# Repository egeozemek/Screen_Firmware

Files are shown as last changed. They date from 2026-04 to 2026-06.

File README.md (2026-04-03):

# Tympanometer

A low-cost tympanometer designed to diagnose hearing loss in children, developed as part of the [Duke BME Design Fellows](https://bme.duke.edu/academics/undergrad/design-fellows/) program at Duke University's Pratt School of Engineering under the supervision of [Dr. Mark Palmeri, MD PhD](https://github.com/mlp6).

- [Duke BME Designers Develop a New Tool to Inexpensively Diagnose Hearing Loss in Children](https://pratt.duke.edu/news/duke-bme-designers-develop-a-new-tool-to-inexpensively-diagnose-hearing-loss-in-children/)
- [Preventing Childhood Hearing Loss Worldwide](https://pratt.duke.edu/news/preventing-childhood-hearing-loss-worldwide/)

---

## Team

**Iris Ye** · **Alisha Gupta** · **James Mu**



---

## Repository Structure

This repo has three active branches, one per contributor:

| Branch | Owner | Focus |
|---|---|---|
| `main` | James Mu | Firmware, OLED display integration, microphone PCB |
| *(Alisha's branch)* | Alisha Gupta | Audio/microphone analog circuit PCB |
| *(Iris's branch)* | Iris Ye | Isolated microphone PCB and analog filtering |

---

## What We've Built

### Firmware & OLED Display — James Mu

Integrated a GME12864-13 (128×64 SSD1306) OLED display into the device running on the nRF52833 DK under Zephyr RTOS. The display renders a real-time tympanogram trace with a split-zone layout:

- **Yellow zone (rows 0–15):** ear canal volume (ECV), static admittance (SA), and peak pressure (PPP)
- **Blue zone (rows 16–63):** tympanogram curve plotted from −400 to +200 daPa

The firmware supports all five standard tympanogram curve types (A, As, Ad, B, C) and currently uses physiologically accurate simulated data. Real ADC input will replace the simulation when the analog front-end is complete.

A custom 3×5 bitmap font is used to minimize flash footprint.

**Hardware:**
- MCU: nRF52833 DK
- Display: GME12864-13 OLED (SSD1306, I2C at 0x3C)
- I2C pins: SDA → P0.27, SCL → P0.26

### Analog Circuitry — Alisha Gupta & Iris Ye

First-iteration PCB designs for the microphone and audio signal chain, focused on filtering out 60 Hz noise from the microphone signal. The team has been exploring different analog filter architectures (including a notch filter redesign) to isolate the tympanometry probe tone from interference.

Key components include:
- **LM4875MM** audio amplifier (SOP-8)
- **TLV313IDBVT** op-amps (×2, TSOT-23-5) for active filtering
- 0603 SMD passive components throughout

A full bill of materials is in [`audio_and_microphone/BOM.csv`](audio_and_microphone/BOM.csv).

---

## Build & Flash (Firmware)

```bash
west build -b nrf52833dk/nrf52833
west flash
```

Requires a [Zephyr RTOS](https://docs.zephyrproject.org/) environment set up with the nRF Connect SDK.

---

*This README was drafted with the assistance of Claude (Anthropic) based on information provided by the team.*

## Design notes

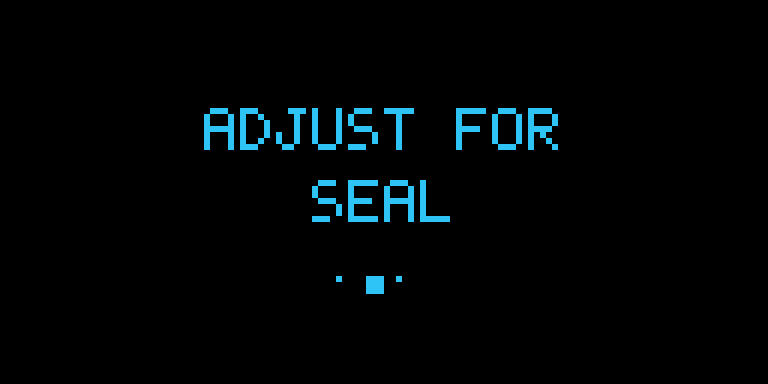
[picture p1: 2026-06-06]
design/_prev_state_seeking_seal.png

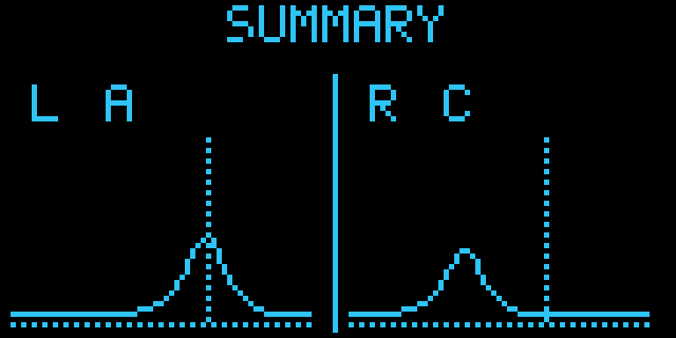
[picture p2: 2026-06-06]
design/_prev_state_summary.png

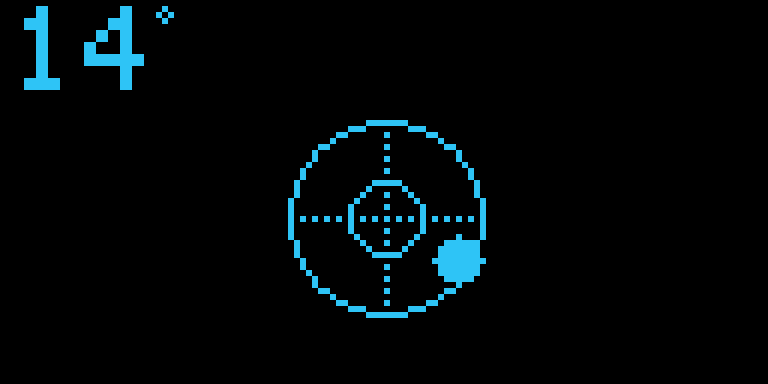
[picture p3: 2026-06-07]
design/_prev_state_level_tilted.png

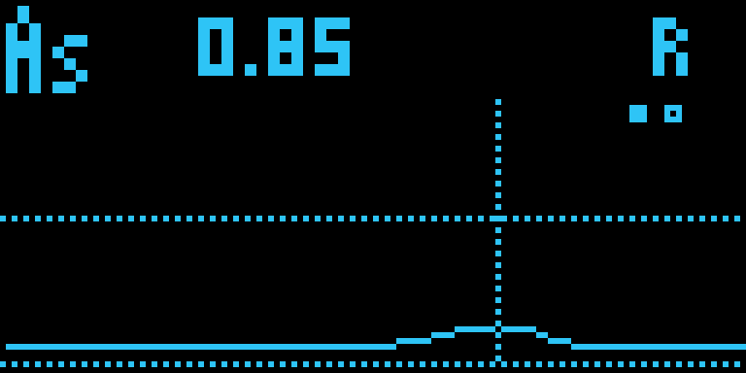
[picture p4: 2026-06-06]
design/_preview_As.png

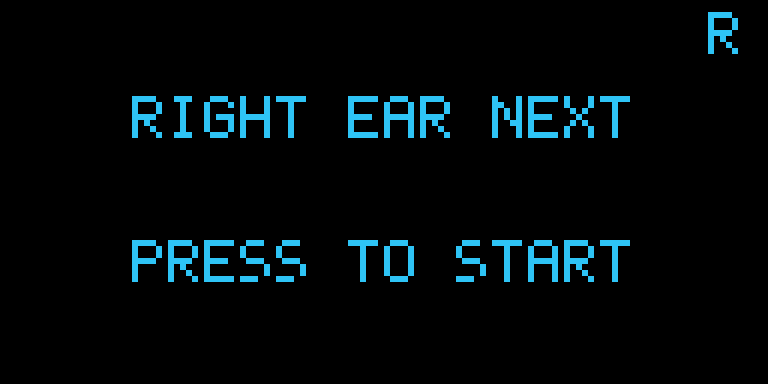
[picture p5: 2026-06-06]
design/_prev_state_rearm.png

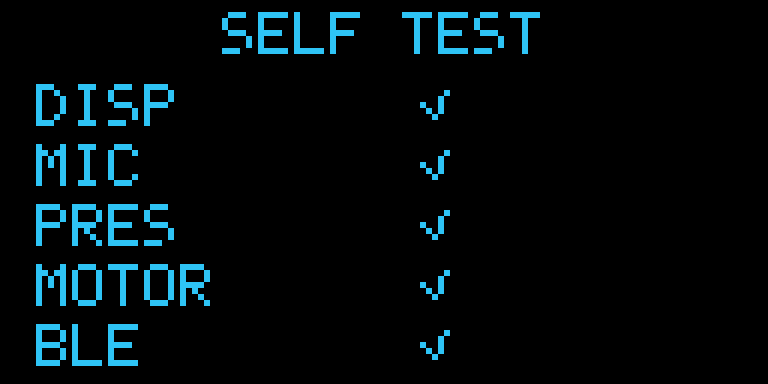
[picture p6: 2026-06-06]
design/_prev_state_boot.png

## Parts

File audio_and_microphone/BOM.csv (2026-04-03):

Id | Designator | Footprint | Quantity | Designation | Supplier and ref
1 | A** | Arduino_Uno_R3_Shield | 1 | Arduino_Uno_R3_Shield
2 | REF** | PinHeader_1x04_P2.54mm_Vertical | 1 | PinHeader_1x04_P2.54mm_Vertical
3 | U3,U1 | TSOT-23-5 | 2 | TLV313IDBVT
4 | U2 | SOP65P490X110-8N | 1 | LM4875MM
5 | R16 | R_0603_1608Metric_Pad0.98x0.95mm_HandSolder | 1 | 820K
6 | R15 | R_0603_1608Metric_Pad0.98x0.95mm_HandSolder | 1 | 22K
7 | R14,R11 | R_0603_1608Metric_Pad0.98x0.95mm_HandSolder | 2 | 27k
8 | R13 | R_0603_1608Metric_Pad0.98x0.95mm_HandSolder | 1 | 13.3k
9 | R12 | R_0603_1608Metric_Pad0.98x0.95mm_HandSolder | 1 | 10k
10 | R10 | R_0603_1608Metric_Pad0.98x0.95mm_HandSolder | 1 | 150k
11 | R9 | R_0603_1608Metric_Pad0.98x0.95mm_HandSolder | 1 | 6.2K
12 | R8,R4 | R_0603_1608Metric_Pad0.98x0.95mm_HandSolder | 2 | 0
13 | R7 | R_0603_1608Metric_Pad0.98x0.95mm_HandSolder | 1 | 300
14 | R6 | R_0603_1608Metric_Pad0.98x0.95mm_HandSolder | 1 | 1.5K
15 | R5 | R_0603_1608Metric_Pad0.98x0.95mm_HandSolder | 1 | 100K
16 | R3 | R_0603_1608Metric_Pad0.98x0.95mm_HandSolder | 1 | 6.98K
17 | R2,R1 | R_0603_1608Metric_Pad0.98x0.95mm_HandSolder | 2 | 6.8K
18 | J6,J5,J4,J3,J1 | PinHeader_1x02_P2.54mm_Vertical | 5 | Conn_01x02
19 | J2 | PinHeader_1x02_P2.54mm_Vertical | 1 | Conn_01x03
20 | C17,C16,C14,C13,C12,C11,C10,C9,C6,C5,C4,C3,C2,C1 | C_0603_1608Metric_Pad1.08x0.95mm_HandSolder | 14 | 0.1u
21 | C15 | C_0603_1608Metric_Pad1.08x0.95mm_HandSolder | 1 | 0.2u
22 | C8,C7 | C_0603_1608Metric_Pad1.08x0.95mm_HandSolder | 2 | 1.0u

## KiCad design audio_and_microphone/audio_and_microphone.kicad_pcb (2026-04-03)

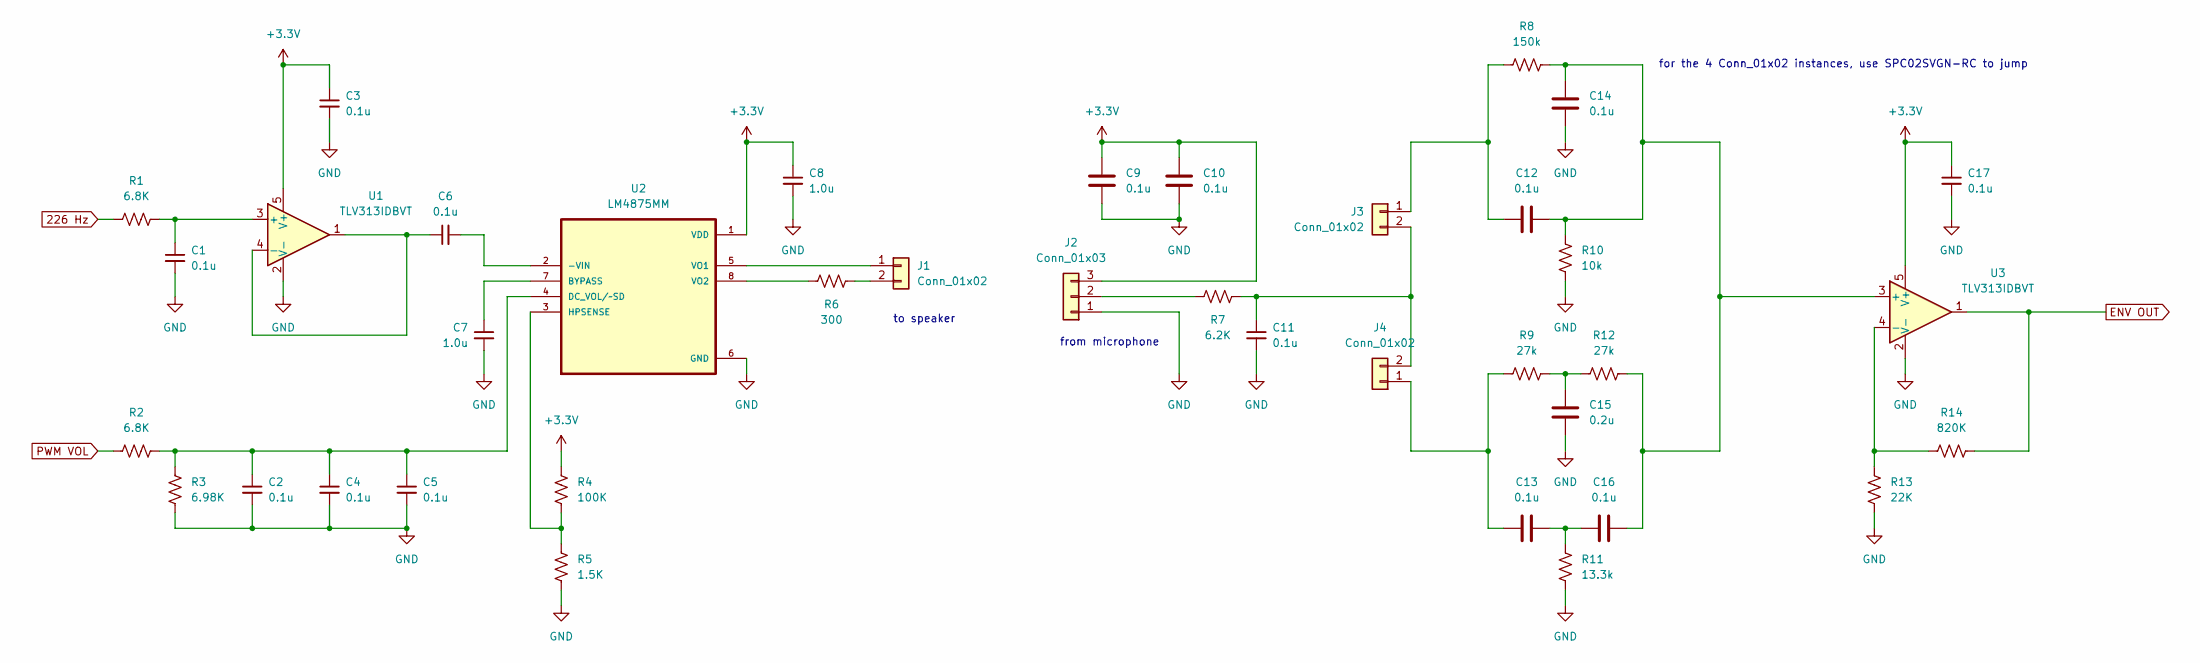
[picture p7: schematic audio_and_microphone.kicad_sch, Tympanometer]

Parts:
C1, C2, C3, C4, C5, C6, C9, C10, C11, C12, C13, C14, C16, C17: 0.1u; CAPC17595_95N_KEM-M
C7, C8: 1.0u; CAPC17595_95N_KEM-M
C15: 0.2u; CAPC17595_95N_KEM-M
J1, J3, J4: Conn_01x02; PinHeader_1x02_P2.54mm_Vertical
J2: Conn_01x03; PinHeader_1x03_P2.54mm_Vertical
R1, R2: 6.8K; RC0603N_YAG-M
R3: 6.98K; RC0603N_YAG-M
R4: 100K; RC0603N_YAG-M
R5: 1.5K; RC0603N_YAG-M
R6: 300; RC0603N_YAG-M
R7: 6.2K; RC0603N_YAG-M
R8: 150k; RC0603N_YAG-M
R9, R12: 27k; RC0603N_YAG-M
R10: 10k; RC0603N_YAG-M
R11: 13.3k; RC0603N_YAG-M
R13: 22K; RC0603N_YAG-M
R14: 820K; RC0603N_YAG-M
U1, U3: TLV313IDBVT; TSOT-23-5
U2: LM4875MM; SOP65P490X110-8N

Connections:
226 Hz: R1.2; also elsewhere on the board
+3.3V: C3.1, C8.1, C9.2, C10.2, C17.1, J2.3, R4.1, U1.5 (V+), U2.1 (VDD), U3.5 (V+); also elsewhere on the board
ENV OUT: R14.1, U3.1; also elsewhere on the board
GND: C1.2, C2.2, C3.2, C4.2, C5.2, C7.2, C8.2, C9.1, C10.1, C11.2, C14.2, C15.2, C17.2, J2.1, R3.2, R5.2, R10.2, R11.2, R13.2, U1.2 (V-), U2.6 (GND), U3.2 (V-); also elsewhere on the board
unnamed: C13.2, C16.2, R11.1
unnamed: C15.1, R9.2, R12.1
unnamed: J1.1, U2.5 (VO1)
unnamed: J1.2, R6.1
unnamed: J2.2, R7.2
unnamed: C12.1, J3.1, R8.1
unnamed: C11.1, J3.2, J4.2, R7.1
unnamed: C13.1, J4.1, R9.1
unnamed: C1.1, R1.1, U1.3 (+)
unnamed: C6.1, U1.1, U1.4 (-)
unnamed: C6.2, U2.2 (-VIN)
unnamed: C7.1, U2.7 (BYPASS)
unnamed: C2.1, C4.1, C5.1, R2.1, R3.1, U2.4 (DC_VOL/~SD)
unnamed: R4.2, R5.1, U2.3 (HPSENSE)
unnamed: R6.2, U2.8 (VO2)
unnamed: C12.2, C14.1, C16.1, R8.2, R10.1, R12.2, U3.3 (+)
unnamed: R13.1, R14.2, U3.4 (-)
PWM VOL: R2.2; also elsewhere on the board

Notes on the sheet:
for the 4 Conn_01x02 instances, use SPC02SVGN-RC to jump
to speaker
from microphone

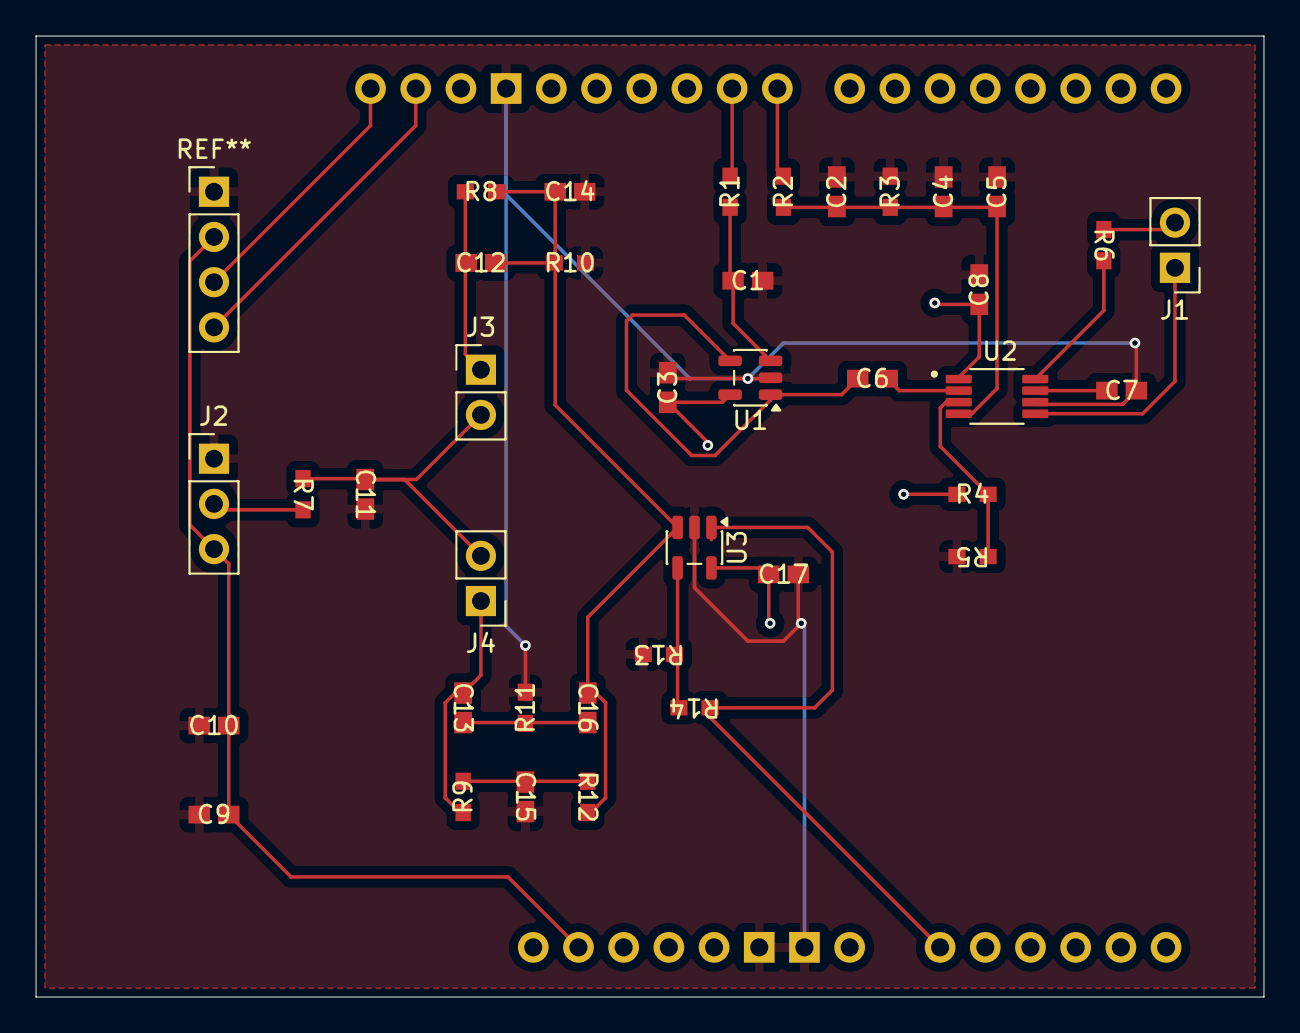
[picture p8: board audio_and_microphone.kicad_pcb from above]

Board: 2 copper layers, 69.0 x 54.0 mm, 39 parts (0 on the bottom side), 22 nets.

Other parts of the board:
A**: Arduino_Uno_R3_Shield

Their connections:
226 Hz: A**.P0.19; also elsewhere on the board
+3.3V: A**.VDD; also elsewhere on the board
ENV OUT: A**.P0.03; also elsewhere on the board
GND: A**.GND; also elsewhere on the board
PWM VOL: A**.P0.17; also elsewhere on the board

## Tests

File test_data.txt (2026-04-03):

Pressure: -417|-384|-351|-319|-290|-261|-227|-194|-165|-137|-109|-82|-56|-32|-7|17|42|69|98|124|147|172|172
Compliance: 0.4|0.46|0.43|0.46|0.46|0.5|0.5|0.53|0.57|0.6|0.7|0.77|0.87|0.97|0.97|0.9|0.7|0.67|0.53|0.46|0.5|0.5|0.5

Full array data for spice simulation Alisha Gupta Iris Ye: 
Pressure: -417|-384|-351|-319|-290|-261|-227|-194|-165|-137|-109|-82|-56|-32|-7|17|42|69|98|124|147|172|172
Compliance: 0.4|0.46|0.43|0.46|0.46|0.5|0.5|0.53|0.57|0.6|0.7|0.77|0.87|0.97|0.97|0.9|0.7|0.67|0.53|0.46|0.5|0.5|0.5
each point would be (pressure, compliance) ie first point would be (-417, 0.4), (-384,0.46), etc. 
the plot below is the trace for this specific ear (this is smoothed so probably won't look as clean but you can use this as a general reference for what the shape should be) 
This is a pretty standard type A. 
Screenshot 2026-01-23 at 11.40.55 PM.png

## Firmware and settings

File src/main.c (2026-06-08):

/* main.c - display test harness: cycles through all screen states on the DK */

#include "display.h"
#include <zephyr/kernel.h>
#include <string.h>          /* strncpy */

/* Build a fake measurement (Lorentzian peak) so we can exercise Results/Summary. */
static void make_demo(struct tymp_results *r, const char *type, char ear,
                      int16_t conf, int16_t ecv, int16_t sa, int16_t tpp,
                      int ppp, int peak_sa, int base, int width)
{
	strncpy(r->type, type, sizeof(r->type));
	r->ear = ear;
	r->confidence_x100 = conf;
	r->ecv_x10 = ecv;
	r->sa_x100 = sa;
	r->tpp_dapa = tpp;
	r->n_points = 64;
	int n = r->n_points;
	int peak = (400 + ppp) * (n - 1) / 600;
	for (int i = 0; i < n; i++) {
		r->points[i].pressure_dapa = (int16_t)(-400 + i * 600 / (n - 1));
		int d = i - peak;
		int k = (d > 0) ? 3 : 2;
		int v = peak_sa * width / (width + d * d * k);
		r->points[i].admittance_x100 = (int16_t)(v < base ? base : v);
	}
}

int main(void)
{
	if (display_init() != 0)
		return -1;                 /* panel not ready - bail */

	static struct tymp_results left, right;
	make_demo(&left,  "A", 'L', 92, 11, 65,    0,    0, 65, 10, 50);  /* Type A */
	make_demo(&right, "C", 'R', 90, 11, 55, -150, -150, 55, 10, 50);  /* Type C */

	for (int i = 0; i < 5; i++) display_set_post(i, true);   /* boot checklist all OK */
	display_set_battery(85);

	while (1) {
		display_set_ear('L');
		display_show_state(DISPLAY_BOOT);          k_sleep(K_SECONDS(2));
		display_show_state(DISPLAY_READY);         k_sleep(K_SECONDS(2));
		display_show_state(DISPLAY_SEEKING_SEAL);  k_sleep(K_SECONDS(2));
		display_show_state(DISPLAY_MEASURING);     k_sleep(K_SECONDS(2));  /* blank */
		display_show_tymp(&left);                  k_sleep(K_SECONDS(6));  /* watch it page */
		display_show_state(DISPLAY_REARM);         k_sleep(K_SECONDS(2));

		display_set_ear('R');
		display_show_state(DISPLAY_SEEKING_SEAL);  k_sleep(K_SECONDS(2));
		display_show_state(DISPLAY_MEASURING);     k_sleep(K_SECONDS(2));
		display_show_tymp(&right);                 k_sleep(K_SECONDS(6));

		display_show_state(DISPLAY_SUMMARY);       k_sleep(K_SECONDS(3));
		display_show_state(DISPLAY_WARNING);       k_sleep(K_SECONDS(2));
		display_show_state(DISPLAY_ERROR);         k_sleep(K_SECONDS(2));

		static const int demo_angles[][2] = {
			{ 12, -7 }, { 0, -14 }, { -12, -7 }, { -14, 0 },
			{ -12, 7 }, { 0, 14 }, { 12, 7 }, { 14, 0 },
			{ 8, 5 }, { 4, 2 }, { 0, 0 },
		};
		for (int i = 0; i < (int)(sizeof(demo_angles)/sizeof(demo_angles[0])); i++) {
			display_set_angle(demo_angles[i][0], demo_angles[i][1]);
			display_show_state(DISPLAY_LEVEL);
			k_sleep(K_MSEC(400));
		}
		display_show_state(DISPLAY_SLEEP);         k_sleep(K_SECONDS(2));
		
	}
}

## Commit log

2026-01-21 uploaded mic schematics
    [Microphone Redesign Schematic.kicad_pcb, Microphone Redesign Schematic.kicad_sch]
2026-01-21 Iris' redesign tympanometer schedmatic design
    [Tympanometer_audio_and_microphone.kicad_pcb, Tympanometer_audio_and_microphone.kicad_sch]
2026-01-21 updated shcematics after meeting 1/21/26
    [Microphone Redesign Schematic.kicad_sch]
2026-01-21 integrated VPWL for microphone testing
    [Tympanometer_audio_and_microphone.kicad_sch]
2026-01-26 1/26 edit SPICE modeling
    [Microphone Redesign Schematic.kicad_sch]
2026-01-26 updated schematic to use compliance data for simulation
    [iris_microphone_only.kicad_pcb, iris_microphone_only.kicad_sch]
2026-01-28 notch filter redesign 1/28
    [Microphone Redesign Schematic.kicad_sch, NotchFilterIsolated.kicad_pcb, NotchFilterIsolated.kicad_sch]
2026-01-28 redesigned notch filter for microphone
    [iris_microphone_only.kicad_sch]
2026-02-09 cleaned filed to merge microphone and audio schematics into audio_and_microphone schematic
    [audio_and_microphone.kicad_pcb, audio_and_microphone.kicad_sch]
2026-02-09 updated gitignore file
    [Microphone Redesign Schematic.kicad_pcb, Microphone Redesign Schematic.kicad_sch, NotchFilterIsolated.kicad_pcb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]
2026-02-09 updated notch filter on microphone
2026-02-09 updated audio and microphone circuit with new redesigned notch filter that was lost
    [audio_and_microphone.kicad_sch]
2026-02-11 Remove KiCad backup/temp files from tracking and update .gitignore
2026-06-03 Overlay for 2.42 (turn off I2C, adjust pins)
2026-06-04 SPI working on safe GPIO pins (P0.04 + A header pins)
2026-06-07 Bugs fixed _ Test Data Working
    [main.c]
2026-06-08 Added angle screen to main.c, fixed display.c
    [main.c]
